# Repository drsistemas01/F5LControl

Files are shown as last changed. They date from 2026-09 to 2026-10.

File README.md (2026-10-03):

<p align="center">
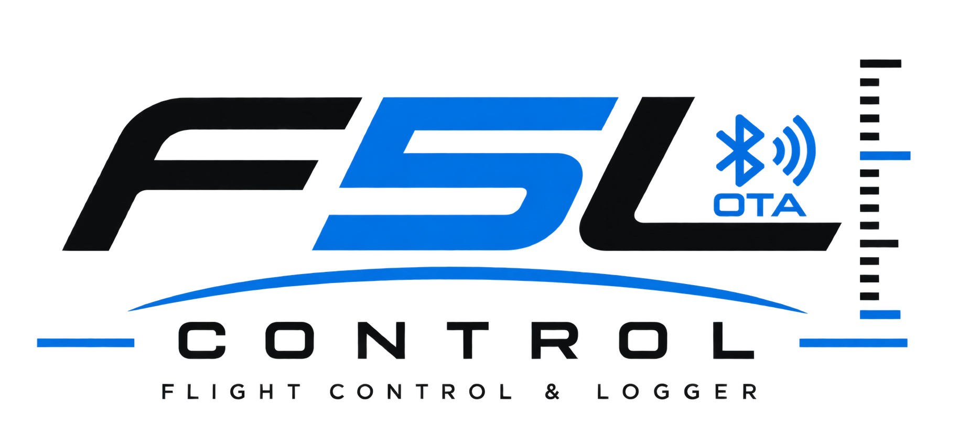
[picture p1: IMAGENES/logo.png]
F5LControl
  
</p>

<p align="center">
  
  
  
  
  
</p>

# F5LControl - Limitador F5L con ESP32-C3

**F5LControl** es un sistema limitador y datalogger para aeromodelismo en la categoría **F5L**, desarrollado sobre **ESP32-C3 Super Mini**.

El proyecto nació con el objetivo de disponer de un equipo **simple, económico y liviano**, capaz de controlar los parámetros de vuelo establecidos para F5L y, al mismo tiempo, registrar la información necesaria para poder **consultar y verificar el vuelo posteriormente**.

---

## Índice

- [Características](#características)
- [El sistema](#el-sistema)
- [Versión actual](#versión-actual)
- [Instalación](#instalación)
- [Uso básico](#uso-básico)
- [Modo Bluetooth](#modo-bluetooth)
- [Actualización por Bluetooth (OTA)](#actualización-por-bluetooth-ota)
- [Indicaciones del LED](#indicaciones-del-led)
- [Indicaciones de la pantalla (OLED)](#indicaciones-de-la-pantalla-oled)
- [Datos guardados en cada vuelo](#datos-guardados-en-cada-vuelo)
- [Hardware](#hardware)
- [Seguridad](#seguridad)
- [Categoría F5L](#categoría-f5l)
- [Carcasa 3D](#carcasa-3d)
- [Imágenes](#imágenes)
- [Tiempo estimado de grabación](#tiempo-estimado-de-grabación)
- [Apoyá el proyecto](#apoyá-el-proyecto)
- [Contacto y soporte](#contacto-y-soporte)
- [Agradecimientos](#agradecimientos)
- [Autor](#autor)

---

## 🎥 Canal de YouTube

Videos sobre **armado, configuración, actualización, pruebas de vuelo, funcionamiento y novedades** del proyecto **F5LControl**.

👉 **[Visitar F5LControl en YouTube](https://www.youtube.com/@F5LControl)**

---

## Características

- Corte de motor por altura.
- Corte de motor por tiempo.
- Registro de altura del vuelo.
- Registro de PWM de entrada desde receptor.
- Registro de PWM de salida hacia ESC.
- Descarga por Bluetooth BLE.
- Actualización de firmware por Bluetooth (OTA) — desde la versión 3.1.0.
- Web de control sin instalar programas.
- Exportación de vuelos `.vlo` y CSV.
- Barra de uso de memoria.
- Compatible con BMP180/BMP280/BME280/BMP580.
- Carcasa imprimible en 3D.

---

## El sistema

**F5LControl está compuesto por dos partes principales:**

### Firmware

Es el software que se instala directamente en el **ESP32-C3** y se encarga del funcionamiento del dispositivo.

Entre sus funciones se encuentran:

* Control del limitador.
* Medición y registro de altura.
* Control de los parámetros de vuelo.
* Registro de vuelos.
* Almacenamiento de los datos para su posterior consulta.
* Comunicación con la interfaz Web Control.

### Web Control

Es la interfaz utilizada para comunicarse con el dispositivo y administrar **F5LControl** de una manera sencilla, sin necesidad de instalar software adicional.

Desde la Web Control es posible:

* Configurar los parámetros del dispositivo.
* Consultar el estado y la información del equipo.
* Acceder al **datalogger**.
* Visualizar los vuelos registrados.
* Analizar y verificar los datos de cada vuelo.

### Contenido del repositorio

Este repositorio público contiene todo lo necesario para instalar y utilizar **F5LControl**:

* Binarios del firmware listos para instalar.
* Web Control.
* Manuales de instalación y utilización.
* Imágenes y documentación del proyecto.
* Normativas relacionadas con F5L.
* Archivos **STL** para impresión 3D de la carcasa.

> **Nota:** el repositorio no incluye el código fuente del firmware.

---

## Versión actual

**VERSION FW:** `3.1.10`  
**VERSION WEB:** `3.1.14`

**Historial de cambios**
- [Historial de cambios del firmware](docs/history_FW.md)
- [Historial de cambios de la web](docs/history_WEB.md)

**¿Cómo actualizo?**

**FW:** seguir el manual de flasheo:  
[Manual_Flasheo_ESP32-C3.pdf](https://github.com/drsistemas01/F5LControl/blob/main/FW/Manual_Flasheo_ESP32-C3.pdf)

**WEB:** descargar el archivo `index.html`:  
[WebControl - descarga directa](https://github.com/drsistemas01/F5LControl/raw/main/WEB%20Control/index.html)

---

## Instalación

### Archivos

**Firmware:** los binarios están en la carpeta `FW/BIN` y el manual de instalación en `FW/Manual_Flasheo_ESP32-C3.pdf`.

**Web de control:** el archivo `WEB Control/index.html`. Abrir con Chrome o Edge compatible con Web Bluetooth.

### Flasheo

> **LEER ANTES DE FLASHEAR**
>
> Antes de conectar la placa o cargar los binarios, leer el manual de instalación del firmware:
>
> `FW/Manual_Flasheo_ESP32-C3.pdf`
>
> Ahí está explicado el paso a paso completo para instalar el FW correctamente.

Cargar los binarios en estas direcciones:

| Dirección | Archivo |
|---|---|
| `0x0` | `bootloader.bin` |
| `0x8000` | `partitions.bin` |
| `0x10000` | `firmware.bin` |

No activar:

- Secure Boot
- Flash Encryption
- Encrypt
- eFuse
- opciones de seguridad permanente

Para uso normal, solo hacer flasheo estándar.

### Qué permite la web

- conectar por Bluetooth BLE
- listar vuelos guardados
- descargar vuelos
- exportar vuelos `.vlo`
- exportar CSV
- ver gráfica de altura
- ver PWM de entrada y salida
- identificar corte de motor
- calcular zoom/inercia posterior al corte
- ver tiempo de vuelo en planeo
- ver uso de memoria
- borrar vuelos
- revisar configuración del firmware

---

## Uso básico

1. Encender la placa con la radio encendida y el acelerador al mínimo.
2. Durante el arranque (aproximadamente 2 segundos), el equipo calibra el mínimo del acelerador y el barómetro.
3. Si detecta barómetro OK, memoria OK, señal PWM válida y mínimo válido, entra en modo vuelo.
4. Si algo falla, entra en modo Bluetooth y muestra el motivo en la pantalla (ver Modo Bluetooth).
5. Para entrar a Bluetooth a propósito (bajar vuelos o configurar), encender con la radio apagada.

> El botón BOOT queda reservado y no interviene en el arranque.

---

## Modo Bluetooth

Para entrar en modo Bluetooth:

1. Encender la placa con la **radio apagada**.
2. Esperar que el LED (parpadeo rápido) o la pantalla (logo de Bluetooth) indiquen Bluetooth activo.
3. Abrir la web de control.
4. Presionar conectar.
5. Elegir el dispositivo ESP32-FLIGHT.

Desde la web se pueden descargar vuelos, revisar la configuración y ver los datos del receptor.

Cuando el equipo entra en modo Bluetooth, el modo vuelo queda bloqueado y el motor no puede arrancar desde el limitador. Para volver a modo vuelo, reiniciar la placa con la **radio encendida** y el acelerador al mínimo.

---

## Actualización por Bluetooth (OTA)

<p align="center">
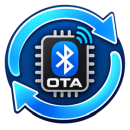
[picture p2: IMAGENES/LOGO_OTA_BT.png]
OTA por Bluetooth
  
</p>

> ✅ Disponible **a partir de la versión 3.1.0** del firmware.

**OTA** (del inglés *Over-The-Air*, "por el aire") significa que el equipo puede **actualizar su firmware por Bluetooth, sin cables ni programas**. Se hace desde la misma **Web Control**, en el celular o la PC.

### Dos formas de actualizar

- **Automática (la más fácil):** con el botón **"Buscar actualizaciones"**, la web mira si hay una versión más nueva publicada y, si la hay, **descarga e instala la última versión disponible** sola, con barra de progreso.
- **Por archivo (avanzada):** subís vos un archivo `firmware.bin` y la web lo instala. Sirve para **volver a una versión anterior** (rollback) o para probar una versión puntual que no sea la última.

En las dos, durante la actualización la pantalla del equipo muestra **UPDATE** con el porcentaje. Si algo se corta o falla, **no pasa nada**: el equipo sigue con la versión anterior (la nueva recién queda activa cuando se verificó completa).

### Seguridad

- El equipo **no está "escuchando" actualizaciones** todo el tiempo: la OTA se inicia **solo cuando vos se lo pedís** desde la web.
- La imagen se valida (tamaño + verificación de integridad) **antes** de activarse.

### ⚠️ Importante: el salto a la 3.1.X se hace una vez por cable

Como la versión **3.1.X cambió la organización interna de la memoria** (para poder tener dos firmwares y hacer OTA seguro), **la primera vez que pasás de una versión 3.0.X a la 3.1.X hay que flashear por USB**.

En ese flasheo por cable es **obligatorio grabar los 3 archivos** siguiendo el **manual de flasheo**:

- `bootloader.bin`
- `partitions.bin`
- `firmware.bin`

> ⚠️ No alcanza con grabar solo el `firmware.bin`: sin la tabla de particiones nueva (`partitions.bin`) el equipo no arranca ni queda habilitado el OTA.

A partir de ese flasheo, **todas las actualizaciones siguientes ya son por Bluetooth**.

> En resumen: **3.0.X → 3.1.X = por cable, los 3 `.bin` según el manual (una sola vez)**. **3.1.X → 3.1.Y en adelante = por Bluetooth (OTA)**.

---

## Indicaciones del LED

| Estado | LED |
|---|---|
| Ventana de arranque | Parpadeo lento |
| Bluetooth activo esperando conexión | Parpadeo rápido |
| Bluetooth conectado | Patrón SOS |
| Vuelo normal | LED fijo |
| Hubo rearranque | Parpadeo rápido |

---

## Indicaciones de la pantalla (OLED)

Si el equipo tiene pantalla, muestra:

| Momento | Pantalla |
|---|---|
| Al encender | Logo **F5L / CONTROL** con la versión |
| Listo para volar | Altura en metros (número grande) + tilde de OK |
| En vuelo (con motor) | Apagada (se enciende sola al aterrizar) |
| Al terminar el vuelo | **VÁLIDO** o **NULO**, alternando **altura máxima** y **zoom** (trepada por inercia) |
| Modo Bluetooth | Logo de Bluetooth + nombre del equipo (**CONECTADO** al vincular la app) |
| Falla de arranque | **E1** sin barómetro · **E2** mínimo del acelerador fuera de rango · **E3** memoria |

La altura a la que la pantalla se enciende sola al aterrizar es configurable desde la web (hasta 10 m; 10 m por defecto).

---

## Datos guardados en cada vuelo

Cada vuelo registra:

- tiempo
- altura
- PWM de entrada desde receptor
- PWM de salida hacia ESC
- motivo de corte

Los vuelos se guardan en memoria interna del ESP32-C3 y se descargan por Bluetooth desde la web.

---

## Hardware

### Placa usada

Placa recomendada:

**ESP32-C3 Super Mini con o sin pantalla OLED integrada**

Compatible con versiones con o sin pantalla.

La pantalla no es necesaria para el funcionamiento del limitador.

Características usadas:

- ESP32-C3
- 4 MB Flash
- USB nativo
- Bluetooth BLE
- GPIO con lógica de 3.3 V

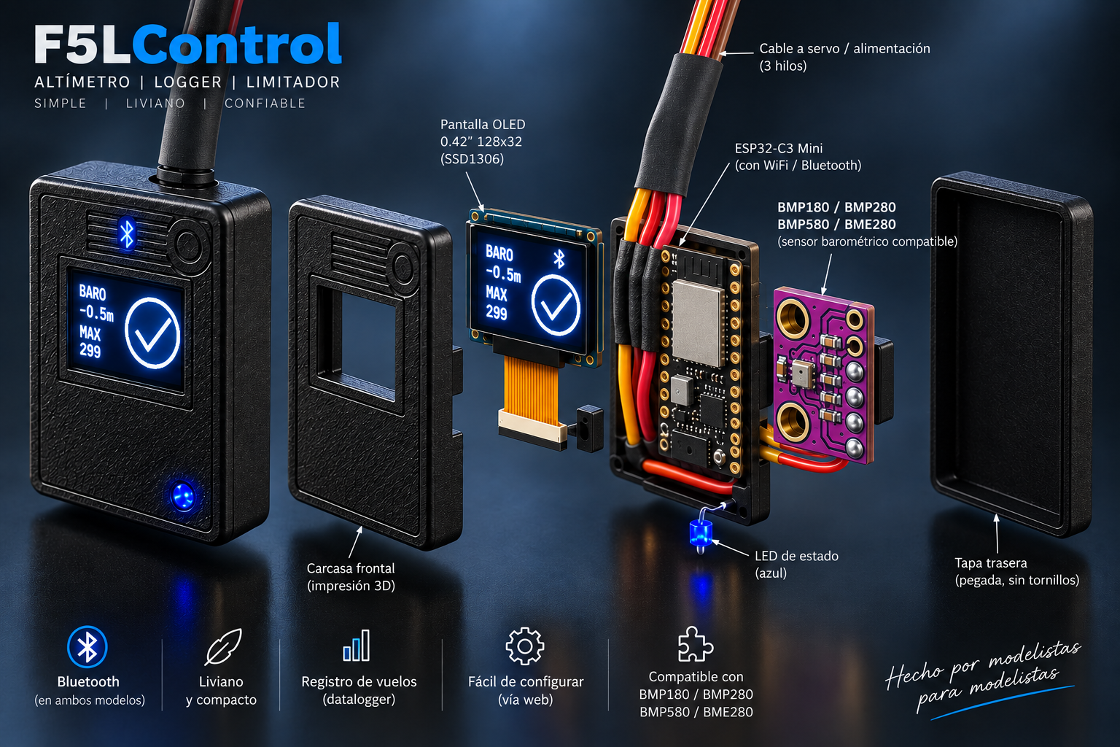
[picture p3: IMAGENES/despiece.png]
Despiece


### Pines

| Función | GPIO |
|---|---|
| Entrada PWM desde receptor | GPIO 3 por defecto. Configurable: GPIO 0, 1, 3, 4, 7 o 10 |
| Salida PWM hacia ESC | GPIO 4 por defecto. Configurable: GPIO 0, 1, 3, 4, 7 o 10 |
| SDA barómetro | GPIO 5 |
| SCL barómetro | GPIO 6 |
| LED de estado | GPIO 8 |
| Botón BOOT (reservado) | GPIO 9 |

Pines permitidos para entrada PWM y salida ESC desde configuración avanzada:

- GPIO 0
- GPIO 1
- GPIO 3
- GPIO 4
- GPIO 7
- GPIO 10

No usar el mismo pin para entrada PWM y salida ESC.

### Conexión básica

**Receptor RC**

| Receptor | ESP32-C3 |
|---|---|
| Señal PWM | GPIO configurado como entrada PWM, por defecto GPIO 3 |
| GND | GND |

La masa del receptor, ESC y ESP32-C3 debe estar en común.

**ESC**

| ESP32-C3 | ESC |
|---|---|
| GPIO configurado como salida ESC, por defecto GPIO 4 | Señal PWM |
| GND | GND |

**Barómetro**

Sensores soportados: BMP180, BMP280, BME280, BMP580. El firmware detecta automáticamente cuál está conectado al iniciar.

| Barómetro | ESP32-C3 |
|---|---|
| VCC | VCC |
| GND | GND |
| SDA | GPIO 5 |
| SCL | GPIO 6 |

### Receptores probados

Voy a ir actualizando esta lista con receptores probados.

Importante: no asumir que cualquier receptor es compatible. Un receptor solo debe conectarse directo si su salida PWM fue verificada en 3.3 V o menos. Si la salida PWM supera 3.3 V, puede dañar el ESP32-C3 y debe usarse adaptación de nivel.

| Marca | Modelo |
|---|---|
| CORONA | R4SF - R6SF - R8SF |
| FRSKY  | RX6R |

Si probaste un receptor, podés informar el resultado a **soporte.f5lcontrol@gmail.com** (marca y modelo, si funcionó, fallas encontradas y sugerencias).

---

## Seguridad

### Advertencia importante sobre PWM

La entrada PWM del receptor va directa al ESP32-C3.

> **ATENCION / CUIDADO**
>
> No todos los receptores son compatibles para conectarlos directo al ESP32-C3.
> Si el receptor entrega una señal PWM superior a 3.3 V, puede quemar el ESP32-C3.

**El pulso PWM del receptor NO debe superar 3.3 V.**

El ESP32-C3 no tolera 5 V en sus GPIO. Si se conecta una señal PWM de 5 V, o cualquier señal superior a 3.3 V, directamente al pin de entrada, se puede quemar la placa.

Algunos receptores entregan PWM a 3.3 V y otros pueden entregar PWM a 5 V. Antes de conectar cualquier receptor al limitador, hay que medir o verificar el nivel real de la señal PWM.

Antes de conectar un receptor:

1. Verificar el nivel de señal PWM.
2. Confirmar que el pulso sea de 3.3 V o menor.
3. No conectar señales PWM superiores a 3.3 V directo al ESP32-C3.
4. Si el receptor entrega PWM de 5 V, usar adaptación de nivel antes de conectarlo.

### Antes de volar

Realizar todas las pruebas de banco siempre **sin hélice**.

Antes de volar verificar:

- señal PWM máxima 3.3 V
- masa común entre receptor, ESC y ESP32-C3
- barómetro detectado
- respuesta correcta del ESC
- sentido correcto del acelerador
- funcionamiento del corte
- batería adecuada
- carcasa correctamente fijada

El uso en vuelo es responsabilidad del usuario.

### Cómo reiniciar el equipo

> ⚠️ **Bajo ningún motivo reinicies la placa con el botón de RESET (RST).**

**Versión CON pantalla (LCD):** para reiniciar, usá **siempre el botón BOOT** manteniéndolo apretado (el tiempo configurado, 2 s por defecto) **con la pantalla encendida** (es decir, en el piso). Eso hace un **reinicio controlado**: primero **cierra y graba el vuelo**, pone el **motor en mínimo (failsafe)** y **recién ahí reinicia**. Seguro y sin perder datos. Se puede habilitar/deshabilitar y ajustar el tiempo desde la web (sección "Pantalla").

**Versión SIN pantalla:** el reinicio controlado con el botón **NO funciona** (necesita la pantalla). En ese caso, **el único medio de reset es desconectar la batería** — **no** usar el botón RST.

**Por qué evitar el RST:** reinicia el micro **de golpe** → si estabas en un vuelo podés **perder los últimos datos** que no se alcanzaron a grabar, y el ESC puede recibir un transitorio en el arranque.

---

## Categoría F5L

F5LControl está diseñado para trabajar con los parámetros usados en F5L.

| Requisito | Valor |
|---|---:|
| Corte por altura | 90 m |
| Corte por tiempo de motor | 30 s |
| Referencia de altura inicial | estabilizada durante la ventana inicial de 2 s |
| Registro posterior del vuelo | sí |
| Verificación posterior del vuelo | sí |
| Barómetro | BMP180/BMP280/BME280/BMP580 |
| Pantalla | Opcional |

El firmware fue diseñado y compilado para cumplir los requisitos funcionales solicitados por FAI/CIAM para esta categoría: limitación por altura/tiempo, registro de datos y posibilidad de verificación posterior.

> Nota: este repositorio no declara una homologación oficial. Para competencia formal, verificar siempre contra la normativa vigente publicada por FAI/CIAM.

Referencia: [FAI Sporting Code - Aeromodelling / CIAM](https://www.fai.org/page/sporting-code)

**Normativas:** la carpeta `NORMATIVAS` incluye documentación de referencia relacionada con F5L y especificaciones del sistema.

---

## Carcasa 3D

Carpeta: `CARCASAS/STL`

Archivos incluidos:

Version sin Pantalla
- `CASE_SIN_LCD_BASE.stl`
- `CASE_SIN_LCD_TAPA.stl`

Version Con Pantalla
- `CASE_OLED_BASE.stl`
- `CASE_OLED_TAPA.stl`

---

## Imágenes

### Web de control

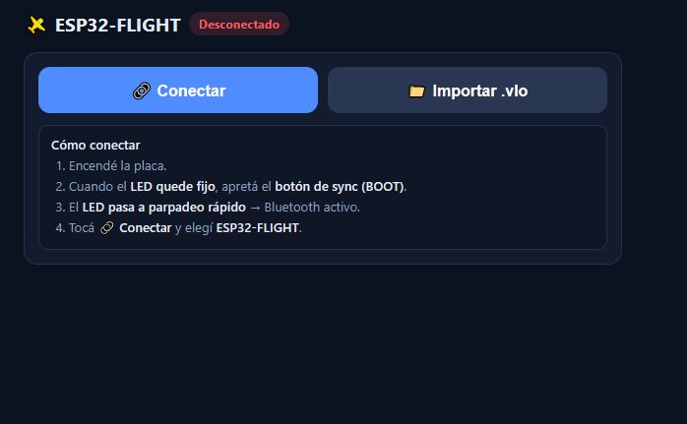
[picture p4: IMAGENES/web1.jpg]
Web 1


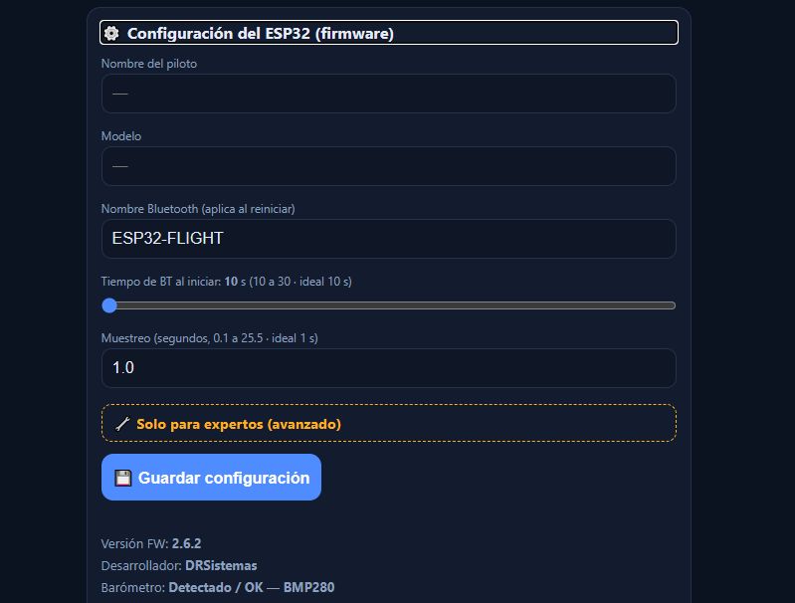
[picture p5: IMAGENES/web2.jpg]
Web 2


### Gráficas

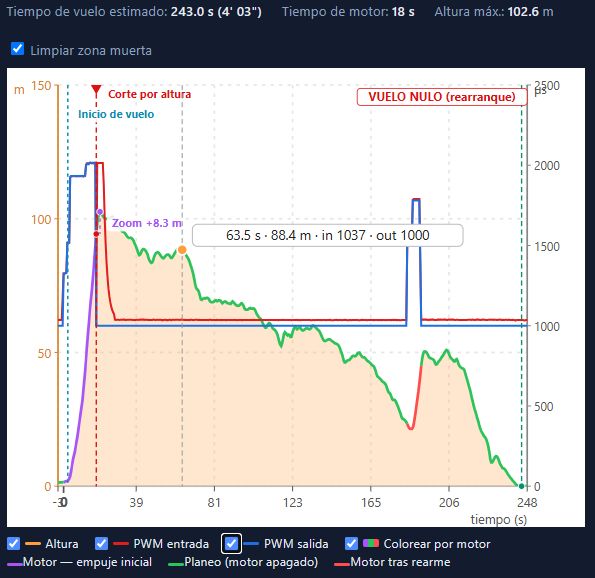
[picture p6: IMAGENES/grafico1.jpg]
Grafico 1


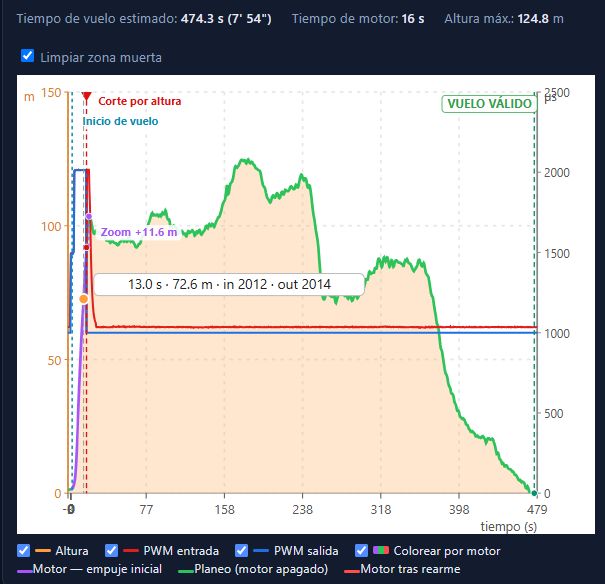
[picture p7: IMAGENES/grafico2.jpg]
Grafico 2


### Carcasa

Version OLED

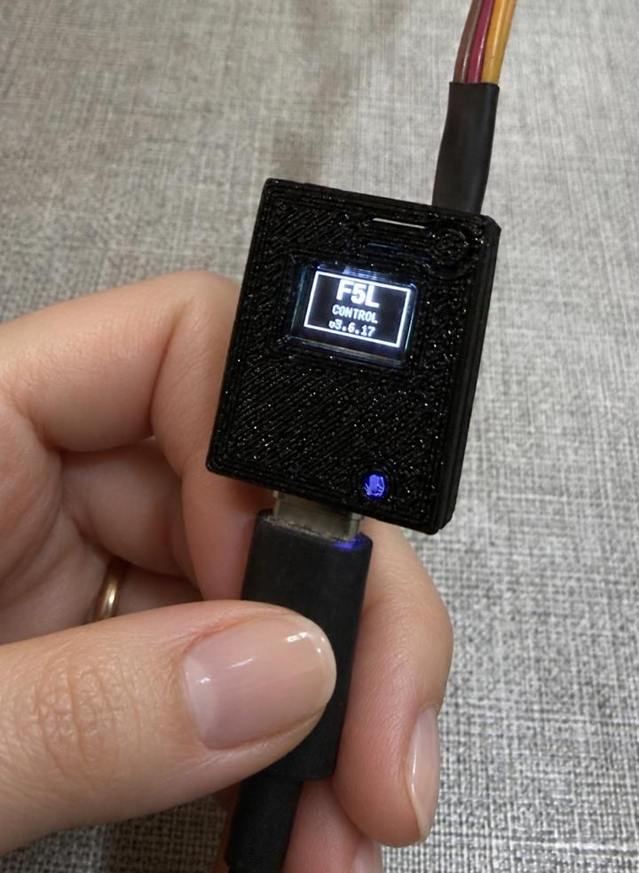
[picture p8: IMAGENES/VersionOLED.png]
Case indoor


Version Sin Pantalla

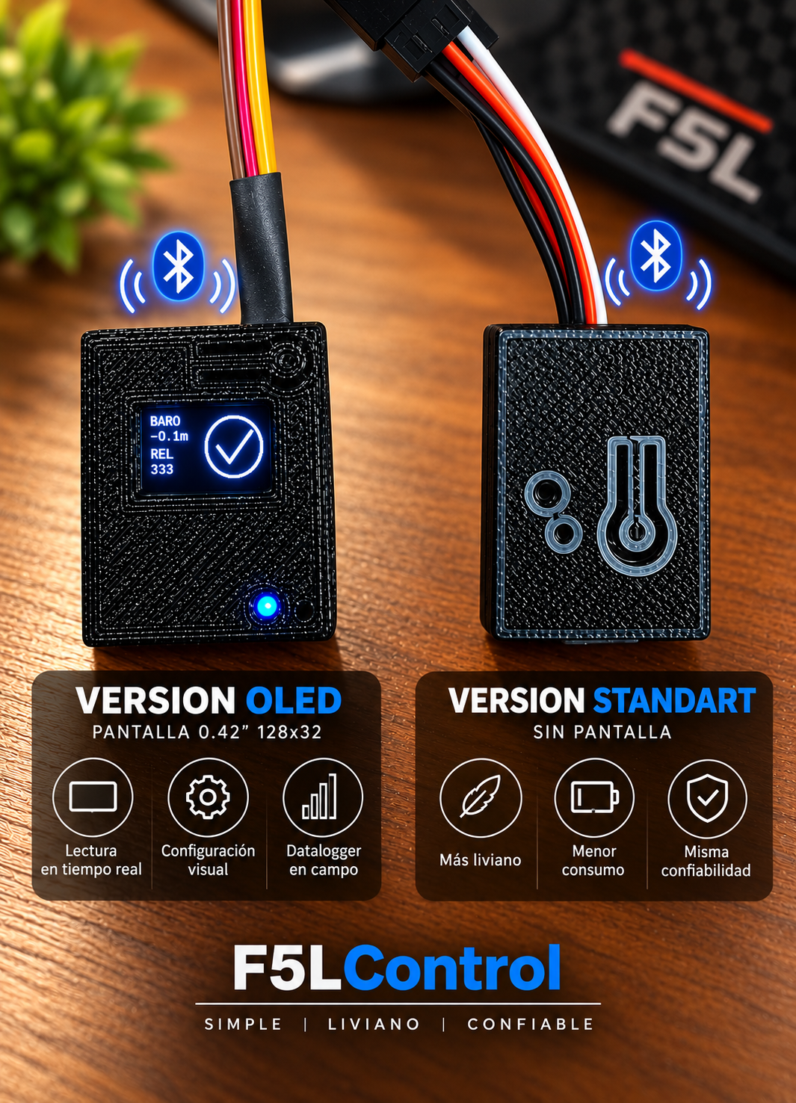
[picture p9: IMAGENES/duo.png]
Case LED


---

## Tiempo estimado de grabación

Los siguientes valores son estimativos. El tiempo real puede variar según la memoria libre disponible, la cantidad de vuelos guardados, el formato interno del archivo y el uso del sistema de archivos.

La tabla está calculada con aproximadamente 896 KB libres y registros VLO2 de 6 bytes.

| Intervalo de muestreo | Tiempo estimado de grabación |
|---:|---:|
| 0.1 s | 4 h |
| 0.5 s | 21 h |
| 1 s | 42 h |
| 2 s | 85 h |
| 5 s | 212 h |

---

## Apoyá el proyecto

F5LControl es un proyecto **libre y gratuito**. La idea es que cualquier aeromodelista pueda armar su propio limitador F5L de forma segura, funcional y a un costo accesible para la categoría, con componentes fáciles de conseguir, firmware ya compilado, web de control y archivos de carcasa para impresión 3D.

**Detrás de cada mejora hay muchas horas de programación, vuelos de prueba, componentes y prototipos.** Si el proyecto te resultó útil, te ayudó en tus vuelos o simplemente te gusta la idea, podés colaborar con el monto que quieras. Cada aporte ayuda a comprar nuevos sensores y placas, realizar más pruebas y seguir sumando mejoras para todos.

### ☕ Invitame un café y apoyá el proyecto

* [Donar con Mercado Pago (donaciones en pesos desde Argentina)](https://mpago.la/1ow62Ju)
* [Apoyar mediante GitHub Sponsors (donaciones internacionales en dólares)](https://github.com/sponsors/drsistemas01)

**Donar es totalmente opcional.** F5LControl seguirá siendo gratuito, completo y disponible para toda la comunidad.

---

## Contacto y soporte

Email: **soporte.f5lcontrol@gmail.com**

Este proyecto es libre y gratuito. No se solicita ningún pago por su uso.

Lo único que se pide es colaborar enviando por email:

- fallas encontradas
- mejoras sugeridas
- receptores probados
- receptores no compatibles o que no funcionaron
- nivel PWM medido
- comentarios o agradecimientos

Esta información ayuda a mantener actualizada la lista pública de receptores probados y a mejorar el proyecto para toda la comunidad.

---

## Agradecimientos

- **Cristian L. (Sunchales, Santa Fe, Argentina)** — Un agradecimiento especial por impulsar la idea inicial de que era posible crear un altímetro de bajo costo y accesible para todos los participantes de la categoría, y por brindarme su asesoramiento desde las primeras etapas del proyecto con la plataforma Arduino.

- **Pablo B. y Guillermo F. (Gran Santiago, Chile)** — Un agradecimiento especial por su aporte en la evolución del proyecto hacia la plataforma ESP32, acompañándome en las pruebas masivas, la validación y las mejoras del código y el hardware.

---

## Autor

**Desarrollo: DRSistemas / JMG**  
**Tandil · Bs. As. · Argentina**  
**GIT: github.com/drsistemas01/F5LControl**  
**Proyecto orientado a aeromodelismo F5L con ESP32-C3.**

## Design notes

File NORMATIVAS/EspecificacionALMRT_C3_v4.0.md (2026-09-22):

# Especificación ALMRT — ESP32-C3 Super Mini

## 1. Alcance

El ALMRT (*Altitude Limiter / Motor Run Timer*) es un dispositivo intercalado entre el receptor RC y el ESC de un planeador eléctrico. Limita el lanzamiento por tiempo de motor y por altura, registra los datos del vuelo y permite su verificación posterior.

Esta especificación es autosuficiente. Define qué debe hacer el dispositivo y sobre qué plataforma. No requiere código ni documentos de referencia: el algoritmo del número de serie (§5.1) incluye constantes, convenciones aritméticas y vectores de prueba verificados.

**Plataforma:** ESP32-C3 Super Mini, ESP-IDF nativo, driver propio del sensor.

---

## 2. Cumplimiento normativo

Categoría de referencia: **F5L**. Los parámetros son configurables en compilación para otras categorías.

### 2.1. De SC4_Vol_EDIC_26 Sección 7 — F5L Time & Height Limiter

| Requisito | Valor | Punto |
|---|---|---|
| Corte de motor | 30 s **o** 90 m, lo que ocurra primero | 2.3 |
| Referencia de altura cero | Máx. 2 s tras aplicar alimentación; sin responder a señal de motor durante ese lapso | 2.5 b/e |
| Salida antes del arranque | ≤ 0,9 ms | 2.5 d |
| Umbral de motor-on | 1,2 ms; histéresis permitida | 2.6.1 / 2.6.2 |
| Tasa de muestreo | ≥ 10 muestras/s | 2.3 |
| Precisión de tiempo | ≤ 0,1 s | 2.3 |
| Precisión de altura | ±2,5 m (2.3.1); "mejor que 2 m" (2.1.1 d) | — |
| Error de cómputo ISA | ±0,5 m | 2.4.5 |
| Rango de presión válido | 750 a 1050 hPa | 2.1.1 d.1 |
| Rango de temperatura | 0 a +50 °C | 2.3.1 |
| Rearranque | Prohibido tras el corte definitivo | 2.6.1 c |
| Display | **Opcional** en F5L | 2.1.2 e |
| Indicación de armado | Claramente visible para el competidor al alimentar | 2.5 a |
| Filtrado | Rechazo de transitorios permitido (2.1.1 c); **suavizado/promediado prohibido** (2.4.6) | — |
| Oversampling del sensor | Permitido | 2.4.7 |
| Alimentación | Desde la salida del receptor hacia el ESC | 2.1.2 c |
| Conectores | JR/Futaba, a prueba de desalineación | 2.1.2 |
| Instalación | ESC siempre en serie con el ALMRT | — |
| Blindaje del sensor | Protegido de luz fuerte y de presión ajena a la altura; venteo adecuado | 2.4.8.2 / 3.1.4 |

**Interpretación de la contradicción sobre filtrado.** El punto 2.1.1 c) exige rechazo de transitorios; el 2.4.6 prohíbe filtrado o suavizado. No son incompatibles: describen operaciones distintas.

- **Rechazo** — descartar una muestra físicamente imposible. La muestra del pico es válida, no se toca. **Permitido.**
- **Suavizado** — promediar muestras vecinas. Altera la muestra del pico. **Prohibido.**

Criterio de corte (2.3.4): ningún procesamiento puede modificar la altura máxima tal como la detectaría la muestra individual que representa el pico.

*Nota: 2.1.1 c) menciona "staging" como ejemplo de evento dinámico, terminología de cohetería — es arrastre de la Sección 2 (modelos espaciales). La doble cifra de precisión (2 m / 2,5 m) tiene el mismo origen. Se diseña contra los 2 m.*

### 2.2. De SC4_VOL_F5_ELECTRIC_26 punto 5.5.12.7

Requisitos no cubiertos por la Sección 7 del EDIC:

- Sin telemetría durante el vuelo de competencia
- Sin cambio de valores de ajuste desde el transmisor
- **Almacenamiento del último vuelo: punto de encendido y de apagado del motor, altura y tiempo**
- El dispositivo debe poder verificarse después del vuelo

5.5.12.8 b): **reset manual**; por transmisor está prohibido. En este diseño el reset es el ciclo de alimentación — quitar y reconectar la ficha, presenciado por el cronometrista.

### 2.3. Contradicción normativa a resolver

El rearranque está **habilitado por defecto** por reglamento GVRA, pero EDIC 2.6.1 c) lo prohíbe.

**Resolución:** parámetro de compilación. Valor por defecto *permitido*. Para presentación a homologación FAI debe compilarse en falso.

---

## 3. Configuración

Todos los parámetros son constantes de compilación. Cualquier cambio requiere recompilar y genera una nueva versión de firmware. **No existe mecanismo de configuración en campo.**

### 3.1. Reglamentarios

| Parámetro | Valor | Justificación |
|---|---|---|
| Tiempo máximo de motor | 30 000 ms | Reglamento F5L |
| Altura máxima de motor | 90 m | Reglamento F5L |
| Duración de cuarentena | 10 000 ms | Práctica de la categoría (ver §11.5) |
| Rearranque | Permitido | Reglamento GVRA |

### 3.2. Acelerador

| Parámetro | Valor | Descripción |
|---|---|---|
| Umbral de arranque | 1200 µs | Apagado → encendido |
| Umbral de apagado | 1190 µs | Encendido → apagado (10 µs de histéresis) |
| Umbral inicial | 1150 µs | Límite superior del acelerador inicial válido en el armado |
| Señal de override | 900 µs | Salida con motor apagado (máximo FAI) |
| Rango mínimo de pulso | 800 µs | — |
| Rango máximo de pulso | 2200 µs | — |
| Rango mínimo de frame | 13 500 µs | Cubre receptores Futaba S-FHSS y modos legacy (~14 ms) con margen |
| Rango máximo de frame | 25 000 µs | Límite superior del rango estándar RC |
| Frescura de acelerador | 300 ms | Límite ante pérdida de señal, no latencia esperada |

**Los tres umbrales no son intercambiables.** Cada uno se usa únicamente en la etapa que indica esta especificación.

### 3.3. Presión

| Parámetro | Valor | Descripción |
|---|---|---|
| Estabilización del sensor | 200 ms | Descarte inicial de lecturas |
| Duración de obtención de presión de piso | 1 000 ms | Total, incluida la estabilización |
| Cantidad mínima de muestras de piso | 10 | Si no se alcanza → bloqueo terminal |
| Intervalo mínimo entre muestras de piso | 40 ms | **Recalcular para C3 — ver §14.2** |
| Frescura de presión | 100 ms | Garantiza ≥10 muestras/s del EDIC |
| Timeout de validez de presión de piso | 300 000 ms | Desde la medición hasta el arranque. Si expira → bloqueo terminal |
| Rango válido de presión | 75 000 a 105 000 Pa | EDIC 2.1.1 d.1 |

### 3.4. Plataforma

| Parámetro | Valor |
|---|---|
| Velocidad del bus I2C | 50 kHz (50 % del estándar, por EMI del brushless) |
| Timeout de transacción I2C (`xfer_timeout_ms`) | 10 ms — **recalcular, ver §14.2** |
| Resolución RMT | 1 MHz (1 cuenta = 1 µs) |
| `signal_range_min_ns` | 2 000 ns (tope de hardware ≈ 3,2 µs) |
| `signal_range_max_ns` | 5 000 000 ns |
| Frecuencia LEDC | 50 Hz |
| Resolución LEDC | 14 bits (máximo del C3) |
| Oversampling de presión | ×8 |
| Oversampling de temperatura | ×8 |
| Filtro IIR del sensor | **Desactivado** (es suavizado — EDIC 2.4.6) |
| Modo del sensor | Normal, standby mínimo |

---

## 4. Hardware

### 4.1. Componentes

| Cant. | Componente | Función |
|---|---|---|
| 1 | ESP32-C3 Super Mini | Procesador, USB-C nativo, LED en GPIO8 |
| 1 | Módulo BMP280 3,3 V, 6 pines | Sensor (con pull-ups I2C y capacitor a bordo) |
| 1 | Resistencia 10 kΩ | Serie, entrada del receptor |
| 1 | Diodo Schottky BAT85 o BAT43 | Recorte de entrada a 3V3 |
| 1 | MOSFET N 2N7000 o BS170 (TO-92) | Salida al ESC |
| 1 | Resistencia 1 kΩ | Pull-up de drain al riel del BEC |
| 1 | Resistencia 10 kΩ | Pull-up de gate a 3V3 |
| 1 | Diodo Schottky 1N5817 o 1N5819 | Serie en alimentación |
| 1 | Capacitor electrolítico 470 µF / 10 V | Después del diodo serie |
| 1 | Capacitor cerámico 100 nF | En paralelo con el electrolítico |
| 1 | Buzzer activo | Indicación de rearranque (opcional) |
| 2 | Cables JR/Futaba (prolongación partida) | Entrada y salida |

### 4.2. Mapa de pines

| Función | Pin | Motivo |
|---|---|---|
| Entrada de acelerador | GPIO3 | Libre de rol de arranque. Crítico: la señal puede estar presente al energizar |
| Salida al ESC | GPIO10 | Libre de rol |
| SDA | GPIO0 | Libre de rol |
| SCL | GPIO1 | Libre de rol |
| Buzzer | GPIO4 | Reservado a JTAG; inactivo en operación |
| LED | GPIO8 | LED de placa, lógica invertida |

**No usar:** GPIO2 y GPIO9 (strapping), GPIO20 y GPIO21 (UART0).

**Ignorar la serigrafía de I2C.** Rotula SDA/SCL en GPIO8/GPIO9: GPIO8 es el LED y ambos son strapping. En el C3 el I2C se asigna por matriz a cualquier pin.

### 4.3. Alimentación

El positivo y la masa van **de conector a conector por cable directo**, sin pasar por las pistas de la placa. La corriente del receptor y los servos no circula por el ALMRT.

En la derivación hacia la placa, en este orden: Schottky en serie → 470 µF + 100 nF → pin 5V.

El diodo cumple cuatro funciones:

1. Retiene la alimentación de la placa ante caídas del riel por transitorios de servo (impide brownout)
2. Protege ante conexión de polaridad invertida
3. Impide que, al conectar el USB para leer el vuelo, se alimenten receptor y servos desde el puerto de la PC
4. Permite operar con BEC de 5 V o 5,5 V

El capacitor absorbe el ruido eléctrico de los servos; el cerámico complementa el filtro. Se documentaron combinaciones de ESC y servos capaces de reiniciar el microcontrolador sin este filtro.

**Advertencia heredada de v3.0 §13:** si el BEC es nominal de 5 V pero entrega menos, el diodo introduce una caída adicional contraproducente. Evaluar si la compatibilidad dual 5 V / 5,5 V es necesaria.

### 4.4. Entrada de acelerador

Señal del receptor → resistencia 10 kΩ → GPIO3. Diodo Schottky desde GPIO3 a 3V3, con la banda del lado del 3V3.

Acepta receptores de 3,3 / 4,8 / 5 / 6 V sin cambiar componentes. Corriente máxima con 6 V: 240 µA.

**No se usa pull-up interno.** El VIH del C3 es 0,75 × VDD = 2,475 V; un receptor de 3,3 V ya lo supera. El pull-up interno de 45 kΩ contra los 10 kΩ serie solo reduciría el margen del nivel bajo.

*El máximo absoluto de entrada del C3 es VDD + 0,3 = 3,6 V. El Schottky recorta en ~3,55 V. Un diodo de silicio común recortaría en 4,0 V, fuera de especificación.*

### 4.5. Salida al ESC

GPIO10 → gate del MOSFET. Source a masa. Drain al hilo de señal del ESC. Pull-up de 1 kΩ del drain al riel del BEC. Pull-up de 10 kΩ del gate a 3V3.

**Lógica invertida:** gate alto → salida baja. El firmware escribe el complemento.

*Por qué pull-up de gate y no pull-down:* durante los ~100 ms de arranque el GPIO está en alta impedancia. El pull-up mantiene el MOSFET conduciendo y la salida en bajo — el ESC no recibe señal válida y no arma.

*Por qué 1 kΩ y no 10 kΩ en el drain:* contra el pull-down interno típico de un ESC (~10 kΩ), un pull-up de 10 kΩ dejaría el nivel alto en la mitad de la tensión del BEC, y el flanco de subida sería lento.

La salida entrega la tensión del BEC, no 3,3 V. Esto garantiza compatibilidad tanto con ESC de lógica 5 V (umbral 3,5 V) como de lógica 3,3 V.

### 4.6. Sensor

VDD a 3V3, GND a GND, SDA a GPIO0, SCL a GPIO1. Montado sobre la placa, dentro del pod del modelo.

El pod cumple el blindaje de luz de EDIC 2.4.8.2 y define el venteo estático de 3.1.4.

El nivel alto del bus lo establecen las resistencias pull-up del módulo a 3,3 V.

### 4.7. Advertencia sobre la placa

La ESP32-C3 Super Mini **no tiene diseño oficial ni fabricante único**. Las variantes difieren en LDO, LED y protecciones.

- Contrastar el pinout con la serigrafía de cada lote
- Leer el modelo del regulador en el encapsulado antes de dar por buenos los 5,5 V del BEC (variantes con ME6211 rondan 6 V de máximo)
- **No hay diodo de protección entre el pin 5V y el VBUS del USB**: nunca alimentar por ambos simultáneamente

---

## 5. Identificación del dispositivo

### 5.1. Número de serie

Hash determinístico de 8 caracteres en base36 sobre los 26 bytes de coeficientes de calibración del BMP280, leídos por I2C desde el registro 0x88.

**Fundamento de la elección.** El C3 tiene MAC única en eFuse, pero **no viene protegida contra escritura de fábrica**: se pueden quemar bits adicionales, y el firmware puede reportar cualquier valor. El hash del sensor es más fuerte: el dato está en el silicio del BMP280, fuera del alcance del firmware. Un verificador que sospeche del firmware carga el suyo y obtiene el valor real.

Como cada dispositivo se ensambla con un único sensor y no se desensambla, el número de serie es único e invariante durante toda su vida útil.

El algoritmo es **invariante**: cualquier reimplementación debe producir exactamente el mismo hash, para preservar la continuidad del registro histórico.

#### 5.1.1. Constantes

| Nombre | Valor |
|---|---|
| OFFSET | `0xCBF29CE484222325` |
| PRIME | `0x100000001B3` |
| ALFABETO | `0-9A-Z` (36 símbolos, en ese orden) |

#### 5.1.2. Convenciones aritméticas

Aritmética entera sin signo de 64 bits con desborde modular (módulo 2⁶⁴). XOR bit a bit. El término `byte[i] × (i+1)` es máximo 6630 y no desborda; el desborde modular aplica al producto por PRIME.

#### 5.1.3. Algoritmo

```
funcion CalcularHashBase36(datos[0..N-1], N) -> cadena de 8 caracteres
    hash = OFFSET                        // uint64
    para i desde 0 hasta N-1:            // índice base 0
        termino = datos[i] * (i + 1)
        hash = (hash XOR termino) * PRIME    // XOR primero, luego multiplicar
        hash = hash mod 2^64
    fin para
    // 8 dígitos base36, del menos significativo al más significativo,
    // escritos de mayor a menor peso (posición 0 = más significativo)
    v = hash
    para p desde 7 hasta 0:
        salida[p] = ALFABETO[v mod 36]
        v = v div 36
    fin para
    devolver salida
fin funcion
```

Notas que eliminan ambigüedad: (1) el orden es XOR y luego multiplicación; (2) el índice es base 0; (3) la reducción equivale a tomar el hash módulo 36⁸, con relleno natural de ceros a la izquierda.

#### 5.1.4. Vectores de prueba

Una implementación correcta debe reproducir exactamente estas salidas sobre 26 bytes de entrada:

| Entrada | Salida esperada |
|---|---|
| `datos[i] = i` (0x00, 0x01, …, 0x19) | `V6MRUXJB` |
| `datos[i] = 0xFF` (los 26 bytes) | `Z71AVNXS` |
| `datos[i] = 0x00` (los 26 bytes) | `TS1HDN0T` |

*Estos tres vectores fueron verificados por ejecución independiente del algoritmo tal como está especificado arriba.*

#### 5.1.5. Manejo de error

Si la transacción I2C falla —NACK, lectura incompleta o timeout— el número de serie es la cadena centinela `ERROR000`.

No se garantiza la unicidad del hash ni que el fabricante produzca coeficientes únicos. Sobre más de 1000 sensores no se registraron colisiones. En caso de colisión, el sensor se descarta y se reemplaza.

### 5.2. Versión de firmware

La versión y los parámetros de la categoría están fijos en el código fuente. Cualquier cambio de parámetros o de comportamiento exige una versión nueva. Versión y parámetros son parte del mecanismo de identificación e integridad.

Como el dispositivo no tiene display, **la revisión de firmware debe estar impresa de forma permanente en el dispositivo** (EDIC 2.1.2).

### 5.3. Reporte serial

Al iniciar, el dispositivo emite por USB CDC un reporte con:

- Versión de firmware y parámetros de configuración activos
- Número de serie del sensor (puede ser `ERROR000`)
- Datos completos del último vuelo registrado, con alturas calculadas y tiempos en segundos

El reporte se emite **exista o no un host conectado**; el proceso continúa sin esperar confirmación. Al terminar se libera el puerto.

Se declara 115200 baudios por continuidad con el procedimiento de verificación existente. En USB CDC el valor es nominal y no afecta la velocidad real.

**El enlace es de solo lectura.** No existen comandos de escritura, por lo que no hay ajustes modificables por ningún medio (satisface EDIC 2.1 d y F5L 5.5.12.7 c).

Con esto se cumple el requisito de poder consultar los datos del último vuelo después del vuelo. El verificador conecta una terminal serial — por ejemplo un teléfono Android con cable OTG y una aplicación de terminal, o cualquier notebook.

**El ALMRT debe desconectarse del modelo antes de conectar el USB.** Esta instrucción debe figurar explícitamente en el procedimiento de verificación.

#### 5.3.1. Formato

```
ALMRT v14.0 - (c) Cristian Leiva

90 metros - 30 Segundos - Rearranque

Sensor           : BMP280

Serie Sensor     : HT7822E6

- Ultimo Vuelo -

Presion Inicial  : 1008.86

Presion Corte    : 998.10

Presion Zoom     : 995.67

Acelerador Inicial: 924

Acelerador Arranque: 1212

Acelerador Corte : 1592

Acelerador Maximo: 1632

Altura Corte     : 90.32

Altura Zoom      : 110.89

Tiempo Inicio    : 22.43

Tiempo Corte     : 10.33

Tiempo Rearranque: 0.00

Tiempo FailSafe  : 0.00
```

---

## 6. Sistema de indicadores

Dos indicadores físicos: **LED** (GPIO8, siempre presente, lógica invertida) y **buzzer** (GPIO4, opcional).

### 6.1. Modos

| Modo | LED | Buzzer |
|---|---|---|
| 0 | Apagado | Apagado |
| 1 | Activo | Inactivo |
| 2 | Activo | Activo |

### 6.2. Patrón de indicación de altura

Representa la altura zoom: la máxima lograda en todo el vuelo con motor más los 10 segundos de cuarentena. Se representa en tres dígitos decimales (centenas, decenas, unidades) emitidos en secuencia y repetidos en loop continuo. La altura es siempre diferencial respecto al piso —no negativa y dentro del rango reglamentario—, por lo que tres dígitos alcanzan.

Un **destello** es el ciclo completo de un estado apagado seguido de un estado encendido. Un **destello largo** es un encendido sostenido de cuatro estados consecutivos sin apagado previo.

- **Dígito 1 a 9:** N destellos consecutivos. El observador los cuenta.
- **Dígito 0 significativo:** un destello largo — cuatro estados encendidos, distinguible por su duración.
- **Dígito 0 no significativo** (ceros a la izquierda): silencio de cuatro estados apagados — misma duración que el destello largo, sin luz, para mantener el ritmo.

Entre cada par de dígitos se inserta una pausa. Al final del tercer dígito, una pausa larga antes de repetir, visualmente distinguible de la pausa entre dígitos.

La duración de cada estado es configurable en compilación y debe ser perceptible a simple vista.

### 6.3. Patrón de indicación de rearranque

Un estado encendido seguido de uno apagado, repetido en loop continuo. Destello simple y veloz, inconfundible con la codificación de dígitos.

### 6.4. Uso por etapa

| Momento | Modo | Contenido |
|---|---|---|
| Al encender | 1 | Altura zoom del vuelo anterior; si `TiempoRearranque > 0` → patrón de rearranque. Permanece hasta el arranque |
| Durante el vuelo activo | 0 | Detenido |
| Post-vuelo sin rearranque | 1 | Altura zoom del vuelo actual |
| Post-vuelo con rearranque confirmado | 2 | Patrón de rearranque, hasta el corte de energía |

La indicación de rearranque persiste en memoria no volátil y reaparece en cada encendido hasta completar un vuelo nuevo sin rearranque.

El LED encendido al alimentar satisface también el requisito de EDIC 2.5 a): indicación claramente visible de que el dispositivo está reseteado y armado.

### 6.5. Jerarquía de verificación de rearranque

Tres medios, en orden de inmediatez:

1. **Buzzer/LED** — audible y visible durante el evento en vuelo y al aterrizar
2. **LED** — visible al encender durante la inspección técnica
3. **Reporte serial** — verificación formal con todos los datos

---

## 7. Sistema de captura de acelerador

### 7.1. Contrato público

La consulta de acelerador retorna exclusivamente:

- **`0`** — no hay información confiable disponible (condición de failsafe, sin excepción)
- **800 a 2200** — valor válido en microsegundos

La decisión de qué hacer ante un `0` corresponde a la etapa que consulta (§11), no a esta función.

### 7.2. Garantías del valor retornado

Cuando el valor es distinto de `0`, cumple simultáneamente:

1. **Integridad del pulso** — la trama contiene exactamente un símbolo. Más de uno indica un flanco espurio que partió el pulso.
2. **Rango físico válido** — entre 800 y 2200 µs.
3. **Frame válido** — período entre flancos de subida consecutivos, dentro del rango configurado.
4. **Frescura** — menos de 300 ms de antigüedad.
5. **Representatividad estadística** — es la mediana de 3 muestras consecutivas válidas.

Si no puede garantizar las cinco, retorna `0`.

**Un pulso y un frame son magnitudes distintas, cada una con su propio rango de validez.** Un pulso pertenece a un frame porque comparten el mismo flanco de subida inicial.

### 7.3. Implementación sobre C3

La captura se realiza con el periférico **RMT en modo recepción** (canales 2 o 3 del C3; los canales 0 y 1 son solo transmisión). El MCPWM no existe en este chip.

**Configuración:**

- Resolución 1 MHz — cada cuenta es 1 µs, unidad natural del PWM de servo
- `signal_range_min_ns` = 2000 ns — filtro de glitches por hardware
- `signal_range_max_ns` = 5 000 000 ns — umbral de cierre de trama

**Sobre el umbral de cierre.** No es la duración del silencio: es cuánto silencio necesita observar el periférico antes de dar la trama por terminada. Debe ser mayor que el pulso más largo (2200 µs) y menor que el silencio más corto (13 500 − 2200 = 11 300 µs). El valor de 5000 µs queda holgado por ambos lados.

**Sobre el filtro de glitches.** Su tope de hardware es ≈3,2 µs (registro de 8 bits contando ciclos del APB a 80 MHz). No puede usarse como umbral de validez de 800 µs — y no debe: el filtro elimina la transición, de modo que un pulso espurio de 400 µs desaparecería sin dejar rastro. Con el filtro en 2 µs ese pulso llega al buffer, se descarta por rango, y puede contabilizarse.

**Ciclo de operación.** El driver detiene el receptor al cerrar cada trama; hay que relanzar la recepción. La ventana disponible es de ~7 ms, margen amplio sobre la latencia de una tarea de prioridad alta.

**Reconstrucción del instante del flanco de subida:**

```
t_flanco = t_cierre − ancho − (signal_range_max_ns / 1000)
```

**Modelo productor/consumidor.** Una tarea productora valida cada trama y publica `{ancho, t_flanco}` en un buffer rodante de las últimas 3 muestras válidas consecutivas. Si una muestra no supera la validación, el conteo de consecutivas se reinicia. La consulta verifica frescura y devuelve la mediana sin demora adicional.

El presupuesto de 300 ms es el límite ante pérdida de señal, no la latencia esperada. En régimen la latencia es de un frame.

### 7.4. Nota sobre la mediana y el retardo

En régimen la ventana de tres ya está llena: entra una muestra, sale la mediana. El retardo es de **un frame**, no de tres. Los tres frames son el llenado inicial, que ocurre segundos antes del lanzamiento.

Un retardo de un frame satisface EDIC 4.2.2 c) —la señal al ESC sigue a la señal de comando— con el mismo orden de retardo que introduce cualquier receptor.

**La mediana no se aplica por magnitud de salto.** Con una llave de dos posiciones el acelerador salta de 1000 a 2000 en un frame, y eso es legítimo. La mediana protege contra un valor espurio aislado, no contra cambios grandes.

---

## 8. Sistema de salida al ESC

### 8.1. Generación

Periférico **LEDC**, 50 Hz, 14 bits (máximo del ESP32-C3).

| Magnitud | Valor |
|---|---|
| Paso | 1,22 µs |
| Duty para 1000 µs | 819 |
| Duty para 2000 µs | 1638 |
| Fórmula | `duty = ancho_µs × 16384 / 20000` |
| Corrección por MOSFET inversor | `duty_escrito = 16383 − duty` |

Se escribe una vez y el hardware repite el pulso indefinidamente, sin intervención de la CPU. Solo se reescribe cuando el valor cambia.

*La resolución de 1,22 µs es peor que los 0,5 µs del hardware AVR anterior y no tiene consecuencia: el ESC no distingue esa diferencia y el EDIC exige 0,1 s de precisión temporal.*

### 8.2. Señal de override

Cuando el dispositivo debe mantener el motor apagado, emite el **acelerador inicial**. Este valor es 900 µs por defecto (máximo FAI para motor apagado, EDIC 2.5 d) y se reemplaza por el valor real obtenido en el armado.

### 8.3. Estado durante el arranque del firmware

Antes de que LEDC quede configurado, el GPIO está en alta impedancia. El pull-up de gate mantiene el MOSFET conduciendo y la salida en bajo. El ESC no recibe pulsos válidos y no arma. Este es el estado seguro y coincide con la lógica invertida en operación.

---

## 9. Medición de presión y cálculo de altura

### 9.1. Contrato de lectura

Mismo contrato que el acelerador: retorna **`0`** si no hay lectura confiable, o la presión compensada en Pascales.

Una lectura es válida si es un número real (no NaN) y está entre 75 000 y 105 000 Pa (EDIC 2.1.1 d.1). Las que no cumplen ambas condiciones cuentan como fallidas.

**Frescura:** menos de 100 ms de antigüedad. Esto garantiza la cadencia mínima de 10 muestras/s del EDIC.

### 9.2. Sensor

**BMP280 exclusivamente.** Direcciones 0x76 o 0x77 según el pin SDO del módulo; el firmware detecta cuál responde validando el Chip ID (registro 0xD0, valor 0x58).

**Driver propio, sobre ESP-IDF.** La compensación se implementa según el procedimiento publicado por Bosch en la hoja de datos del sensor. Para homologación, el EDIC exige la hoja de datos del fabricante como documentación de respaldo; un driver que sigue ese procedimiento es directo de defender.

**Configuración:** modo normal, muestreo continuo y autónomo, oversampling de presión ×8, de temperatura ×8, filtro IIR desactivado, standby mínimo. La lectura solo cosecha el último dato disponible.

El oversampling está expresamente permitido por EDIC 2.4.7. El filtro IIR desactivado no es opcional: es suavizado, prohibido por 2.4.6.

La temperatura se mide internamente para la compensación, por lo que la presión devuelta ya está compensada.

### 9.3. Rechazo de transitorios

Permitido y exigido por EDIC 2.1.1 c). Se descarta una muestra cuya tasa de cambio contra la anterior sea físicamente imposible para un planeador.

El criterio debe ser por **tasa de cambio físicamente imposible**, no por desviación estadística respecto de un promedio — esto último sería suavizado encubierto. El umbral debe documentarse: es lo que un evaluador va a querer ver.

**Prohibido:** promediar, media móvil, o cualquier operación que altere la muestra que representa el pico.

### 9.4. Cálculo de altura

Fórmula ISA del EDIC 2.4.1:

**h = 44330,76923 × (1 − (P / P₀)^0,190266669)**

Donde P es la presión medida y P₀ la presión de referencia del piso, ambas en Pascales. El cálculo es siempre diferencial respecto al piso.

Constantes: K1 = 44330,76923 m; K2 = 0,190266669.

**Las variables se implementan como `float` de 32 bits. Nunca `double`.** El ESP32-C3 no tiene FPU y emula el punto flotante por software; la doble precisión es sustancialmente más lenta. La precisión de `float` es suficiente para el ±0,5 m que exige EDIC 2.4.5.

*El ATmega328P tampoco tenía FPU, así que esto no es una regresión: el C3 emula 32 bits a 160 MHz contra 8 bits a 16 MHz.*

---

## 10. Persistencia

Se utiliza **NVS** sobre la flash interna. El almacenamiento por clave elimina la necesidad de asignar direcciones manualmente.

### 10.1. Datos persistidos

| Dato | Descripción |
|---|---|
| Presión inicial | Promedio de al menos 10 lecturas de presión de piso al arrancar. Referencia de todos los cálculos de altura |
| Presión de corte | Presión mínima registrada durante el vuelo con motor. Se inicializa a la presión inicial |
| Presión zoom | Presión mínima durante el vuelo con motor y los 10 s de cuarentena. Se inicializa a la presión inicial |
| Acelerador inicial | Valor de motor apagado del piloto. 900 µs por defecto, reemplazado al completar el armado |
| Acelerador de arranque | Valor en el momento del arranque |
| Acelerador de corte | Último valor antes del corte. Se inicializa al valor de arranque |
| Acelerador máximo | Máximo registrado durante el vuelo. Se inicializa al valor de arranque |
| Tiempo de inicio | Timestamp del arranque, en milisegundos |
| Tiempo de corte | Milisegundos desde el arranque hasta el corte |
| Tiempo de rearranque | Milisegundos desde el arranque hasta el rearranque. 0 si no hubo |
| Tiempo de failsafe | Milisegundos desde el arranque hasta el primer failsafe. 0 si no hubo |

### 10.2. Momento de escritura

Los datos se persisten **al finalizar la cuarentena**. El registro sobrevive al ciclo de alimentación y se sobrescribe recién en el vuelo siguiente. Alimentar el dispositivo nunca borra el registro: si lo hiciera, sería imposible cumplir F5L 5.5.12.7 e).

### 10.3. Precaución de IRAM

El ESP32-C3 es monocore. Durante una escritura a flash se detienen las interrupciones no marcadas como seguras para IRAM, por decenas de milisegundos en el peor caso.

**El callback de RMT y todo lo que invoque deben estar en IRAM** (`ESP_INTR_FLAG_IRAM`). Los datos constantes que el manejador use requieren `DRAM_ATTR` — el compilador puede ubicar en flash una constante aunque no esté marcada `const`.

*Mitigación de arquitectura:* la escritura ocurre al cerrar la cuarentena, con el vuelo con motor ya terminado y la salida al ESC fija por hardware. Solo es crítico si el rearranque está habilitado, porque en ese caso el acelerador sigue vigilándose después del corte.

---

## 11. Etapas operativas

El dispositivo ejecuta una secuencia lineal de etapas, sin retorno. El **bloqueo terminal** es una condición sin salida: el dispositivo mantiene el acelerador en el valor de acelerador inicial indefinidamente hasta que se corte la energía.

La etapa es una variable de estado compartida entre tareas. El bloqueo terminal es un estado que todas las tareas respetan, no un bucle infinito.

### 11.0. Acciones ante un valor `0` de las funciones de adquisición

| Etapa | Magnitud | Acción ante `0` |
|---|---|---|
| Presión de piso (11.1) | Presión | Descartar la muestra: no cuenta para el promedio |
| Armado / Arranque (11.2 / 11.3) | Acelerador | No se cumple la condición de avance; se sigue esperando (sujeto al timeout de validez de piso) |
| Vuelo con motor (11.4) | Acelerador | Failsafe: corte (override) + registro de tiempo de failsafe |
| Vuelo con motor (11.4) | Presión | Corte (override) + registro de tiempo de failsafe |
| Cuarentena (11.5) | Presión | Descartar la muestra |
| Post-vuelo (11.6) | Acelerador | Failsafe post-rearranque: override + registro de failsafe (1ª vez) |

### 11.1. Inicialización

**Configuración de hardware.** Pines, RMT, LEDC, I2C, NVS. Salida al ESC en 900 µs (override FAI).

**Lectura de NVS.** Carga los datos del último vuelo registrado.

**Indicación del vuelo anterior.** Modo 1 (solo LED). Si `TiempoRearranque > 0` → patrón de rearranque; si no → altura zoom del vuelo anterior, redondeada al entero más cercano y clampeada a 0–999. Permanece activa hasta el arranque.

**Verificación del sensor y número de serie.** Intenta el BMP280 en 0x76 y 0x77. Lee los 26 bytes de calibración desde 0x88 y calcula el número de serie. Si el sensor no responde, o falla la lectura de calibración → `ERROR000`.

**Reporte serial.** Emite el reporte incluyendo el número de serie. No bloqueante: no espera host.

**Bloqueo terminal.** Si el número de serie es `ERROR000` → bloqueo terminal inmediato.

**Establecimiento de referencia de altura.** Estabiliza el sensor 200 ms descartando lecturas. Luego, durante el resto de los 1000 ms, obtiene todas las muestras válidas posibles respetando el intervalo mínimo entre muestras. Si no se alcanzan 10 muestras válidas → bloqueo terminal. El promedio es la presión de referencia; `PresionCorte` y `PresionZoom` se inicializan a ese valor.

Inmediatamente arranca el contador de validez de presión de piso.

**Restricción de EDIC 2.5 b/e:** toda esta etapa debe completarse dentro de los 2 s desde la aplicación de alimentación, y durante ella el dispositivo no debe responder a ninguna señal de motor. Ver §13.1 sobre el presupuesto de arranque.

### 11.2. Armado

Espera que la consulta de acelerador retorne un valor distinto de `0` y menor al **umbral inicial**. El contador de validez sigue corriendo; si expira → bloqueo terminal.

Al obtenerlo, ese valor reemplaza al acelerador inicial (900 µs) y se replica inmediatamente a la salida del ESC.

### 11.3. Arranque

Espera acelerador **mayor al umbral de arranque**. El contador de validez sigue corriendo; si expira → bloqueo terminal.

Al detectar el arranque:

- Se registra el timestamp de inicio
- Se registran acelerador de arranque, de corte y máximo, todos al valor de arranque
- `PresionCorte` y `PresionZoom` se inicializan a `PresionInicial`
- Tiempos de corte, rearranque y failsafe se inicializan en cero
- El servicio de indicadores se detiene (modo 0)

### 11.4. Vuelo con motor

Monitoreo continuo:

**Acelerador.** Se replica al ESC en tiempo real. Se actualizan acelerador máximo y de corte.

**Failsafe RC.** Si la consulta retorna `0` → corte, registro de tiempo de failsafe, fin de etapa.

**Presión.** Muestreo continuo; actualiza `PresionCorte` y `PresionZoom` con el mínimo. Si la lectura retorna `0` → corte, registro de failsafe, fin de etapa.

**Corte reglamentario** — cualquiera de los tres termina la etapa:

- Altura calculada ≥ altura máxima configurada
- Tiempo transcurrido ≥ tiempo máximo configurado
- Acelerador ≤ umbral de apagado (el piloto corta)

Al salir, el acelerador se fija en el valor inicial.

*El corte por altura lo detecta la tarea de presión; el corte por tiempo y por acelerador, la tarea de acelerador. La rutina de corte debe ser atómica: dos tareas pueden alcanzarla.*

### 11.5. Cuarentena

10 segundos sin posibilidad de rearranque. El acelerador se mantiene en el valor inicial.

Continúa el muestreo de presión actualizando `PresionZoom` si se registra un nuevo mínimo.

Al finalizar se persisten todos los datos en NVS.

*Nota normativa: la ventana de 10 s proviene de la práctica de la categoría. El texto de la Sección 7 define la ventana de detección de pico hasta el cruce de la altura requerida (2.5), lo cual deja sin cerrar el caso de corte por tiempo por debajo de 90 m — que es el habitual. Los 10 s también figuran en 4.2.3 del EDIC, pero ese apartado describe el procedimiento de F5J. Ver §14.1.*

### 11.6. Post-vuelo

El acelerador se mantiene en el valor inicial. Los indicadores pasan a modo 1 mostrando la altura zoom del vuelo actual.

**Sin rearranque habilitado:** bloqueo terminal.

**Con rearranque habilitado:** el rearranque es un mecanismo de seguridad que permite al piloto recuperar el control del acelerador a costa de invalidar el vuelo.

Cuando el acelerador regresa a un valor menor al umbral inicial, el piloto puede optar por usar el mecanismo. Si luego sube por encima del umbral de arranque, el rearranque queda confirmado:

- Se registra el tiempo de rearranque
- Se persiste en NVS
- Los indicadores pasan a modo 2 con patrón de rearranque, para alertar al juez
- A partir de ahí el piloto tiene control directo del acelerador, replicado sin restricciones

El tiempo de rearranque se registra **una única vez** (primer rearranque confirmado); las activaciones posteriores no lo modifican. El tiempo de failsafe también se registra una única vez.

**Failsafe post-rearranque.** Si la consulta retorna `0` → acelerador inicial al ESC, y se persiste el failsafe solo la primera vez. El dispositivo sigue sensando. Si la señal regresa por encima del umbral inicial, se mantiene el acelerador inicial hasta que el piloto baje por debajo de ese umbral, momento en que recupera el control directo. El ciclo se repite hasta el apagado.

---

## 12. Arquitectura de firmware

### 12.1. Tareas

| Tarea | Prioridad | Función |
|---|---|---|
| Acelerador | Alta | Consume tramas RMT, valida, publica mediana, replica al ESC, evalúa umbrales |
| Presión | Media | Cosecha el sensor, valida, publica con timestamp, detecta corte por altura |
| Indicadores | Baja | Genera los patrones de LED y buzzer |

El callback de RMT corre en contexto de interrupción, en IRAM: encola la trama y relanza la recepción. No bloquea.

Las esperas son bloqueos de FreeRTOS —la tarea se suspende y el planificador cede la CPU—, no espera activa.

### 12.2. Modelo de adquisición

Cada productor publica `{valor, timestamp, válido}`. Cada consumidor verifica la antigüedad contra su presupuesto de frescura y obtiene el valor o el centinela `0`.

*Esto reemplaza el esquema de "función con presupuesto y reintentos internos" del diseño AVR, que existía porque en un bucle único una lectura lenta bloqueaba todo el sistema. Con tareas independientes ese riesgo no existe, y el presupuesto pasa a ser un criterio de frescura, que es lo que realmente importa.*

### 12.3. Fuente de tiempo

El temporizador de sistema, derivado del reloj principal y por lo tanto del cristal externo. **No usar nada apoyado en el oscilador RC interno.**

Con 10 ppm, el error sobre 30 s es de 0,3 ms. El retardo dominante es la detección del arranque: hasta un frame (25 ms). Ambos muy dentro de los 0,1 s del EDIC.

### 12.4. Configuración del proyecto

Todo viaja en el binario; la placa no se modifica físicamente.

| Opción | Valor | Motivo |
|---|---|---|
| `CONFIG_BOOTLOADER_LOG_LEVEL` | Mínimo | Reduce el tiempo de arranque |
| `CONFIG_LOG_DEFAULT_LEVEL` | Mínimo | Ídem |
| `CONFIG_ESPTOOLPY_FLASHMODE` | QIO | Casi duplica la velocidad de carga desde flash |
| `CONFIG_ESP32C3_RTC_CLK_CAL_CYCLES` | 0 | Omite la calibración del reloj lento |
| `CONFIG_BOOTLOADER_SKIP_VALIDATE_ON_POWER_ON` | **NO usar** | Ahorra tiempo pero omite la verificación de integridad del firmware, que es parte de lo que se homologa |

---

## 13. Limitaciones conocidas

### 13.1. Presupuesto de arranque

Los 2 s de EDIC 2.5 b) se cuentan desde la aplicación de alimentación, no desde que corre el firmware. El arranque del C3 —bootloader de ROM, bootloader de segunda etapa, verificación de imagen, inicialización— consume parte de ese presupuesto.

Con la configuración de §12.4, hay un caso reportado en ESP32-C3 de ~96 ms de arranque total. Contra los 1200 ms de la referencia de altura, quedan unos 700 ms de margen.

**Sin esa configuración el arranque puede consumir el presupuesto entero.**

### 13.2. Validez de la presión de piso ante cambios atmosféricos

La presión de piso se mide una única vez; su validez se degrada con el tiempo. El timeout configurable obliga al piloto a reiniciar si no arranca dentro del plazo.

### 13.3. Unicidad del número de serie

La unicidad del hash no está garantizada matemáticamente y el fabricante no garantiza coeficientes de calibración únicos. En la práctica, sobre más de 1000 sensores no se registraron colisiones. En caso de colisión, descartar y reemplazar el sensor.

### 13.4. Tasa de muestreo ante falla del bus I2C

Ante una falla generalizada y reiterada del bus podría no sostenerse la tasa mínima de 10 muestras/s del EDIC. En condiciones normales la tasa supera ampliamente el mínimo.

El driver de I2C del C3 devuelve `ESP_ERR_TIMEOUT` ante bus ocupado o falla de hardware; el timeout es un argumento de la llamada. Dispone además de `glitch_ignore_cnt`, filtro de hardware sobre las líneas, aplicable al ruido del brushless. Si el bus queda trabado, la recuperación manual es pulsos de reloj hasta liberar SDA, condición de stop, y reinicialización del driver.

### 13.5. Resolución de la salida PWM

1,22 µs por paso, contra 0,5 µs del hardware AVR anterior. Sin consecuencia funcional: el ESC no distingue esa diferencia.

---

## 14. Puntos abiertos

### 14.1. Ventana de detección de pico

La ventana de 10 s posterior al corte proviene de la práctica de la categoría, no del texto de la Sección 7. Conviene consultarlo al EDIC antes de presentar a homologación, porque define qué altura se registra.

### 14.2. Recálculo de presupuestos de tiempo

Los siguientes valores están heredados de la plataforma AVR con la biblioteca `Wire` y deben recalcularse con mediciones sobre C3:

- Intervalo mínimo entre muestras de piso (40 ms)
- Timeout de transacción I2C (10 ms)
- Frescura de presión (100 ms)

### 14.3. Tratamiento del reinicio anómalo

`esp_reset_reason()` distingue encendido limpio de brownout, watchdog de tareas, watchdog de interrupciones y pánico.

Un reinicio en vuelo haría que el dispositivo tome referencia de altura cero en el aire y rehabilite el motor. El hardware de §4.3 cubre la causa de alimentación; falta definir el tratamiento de las causas de software.

Opción planteada, pendiente de elaborar: bloqueo terminal ante cualquier causa distinta de encendido limpio, con patrón de indicación propio y registro en NVS.

---

## 15. Sin verificar

Lo siguiente sostiene decisiones de esta especificación y **no fue confirmado**:

| Ítem | Impacto si no se cumple |
|---|---|
| Tasa efectiva del BMP280 con ×8 y standby mínimo | Si no supera 10 Hz con margen, revisar oversampling y presupuesto de ruido |
| Tiempo de arranque real en la placa concreta | Si excede ~800 ms, acortar la ventana de presión de piso |
| Límite de entrada del LDO de la Super Mini | Variantes con ME6211 rondan 6 V; el BEC entrega 5,5 V |
| Si el driver de RMT del C3 ubica su ISR en IRAM por defecto | Determina el trabajo de §10.3 |
| Deriva térmica del BMP280 montado en el pod | Estimada en ~25 cm sobre un presupuesto de 2 m |

Ninguno invalida la elección de plataforma. Son puestas a punto.

---

## 16. Prompt de generación de código

*Genera TODO el proyecto siguiendo esta especificación al pie de la letra y con el código más eficiente posible para el hardware definido.*

*Fuente de verdad: esta especificación y este prompt mandan siempre. Si te entrego un proyecto de referencia, úsalo solo como guía; ante cualquier diferencia, gana la especificación y el prompt. Los valores por defecto son los de las tablas de la sección 3. Esta especificación es autosuficiente: el algoritmo de número de serie (5.1) incluye constantes, convenciones aritméticas y vectores de prueba verificados, por lo que no necesitás código de referencia para reproducirlo.*

*NO portes código del proyecto AVR anterior. La funcionalidad es la misma; la implementación debe aprovechar el hardware nuevo. Cualquier patrón que exista solo por limitaciones del ATmega328P debe descartarse.*

*El código de referencia NO es modelo de estilo. Aunque use retornos tempranos u otros patrones, no los imites: el estilo lo define este prompt.*

*Antes de empezar, hacé TODAS las preguntas que tengas. Una vez que arrancás, no preguntes más: ante una ambigüedad menor tomá la interpretación más fiel a la especificación y documentá el supuesto como comentario en el código.*

*Antes de escribir el primer archivo, analizá el sistema completo, identificá los datos que se producen y consumen entre módulos, y documentá las decisiones de optimización. Luego, para cada archivo: (1) citá los puntos de la especificación que cubre, (2) verificá que no haya redundancias, (3) escribí el código, (4) verificá que cada garantía esté implementada y que no haya operaciones redundantes. Todo ese análisis va como comentarios en el código, no en el chat.*

*Plataforma: ESP-IDF nativo sobre ESP32-C3 Super Mini. No uses el framework Arduino ni bibliotecas de terceros para el sensor: el driver del BMP280 se implementa según el procedimiento de compensación de la hoja de datos de Bosch.*

*El sensor es exclusivamente BMP280, en 0x76 o 0x77. Validá el Chip ID (registro 0xD0 = 0x58).*

*Marcá con IRAM_ATTR el callback de RMT y todo lo que invoque; usá DRAM_ATTR en los datos constantes que ese camino toque. Asigná la interrupción con ESP_INTR_FLAG_IRAM. Dejá un comentario explicando por qué.*

*Usá float de 32 bits, nunca double: el ESP32-C3 no tiene FPU.*

*La versión del proyecto es la 14.0; el nombre del proyecto debe contenerla y debe verse reflejada internamente donde corresponda.*

*Estructura: cada etapa operativa en su propio módulo; las funciones comunes se agrupan por afinidad funcional. La lectura de acelerador es conceptualmente distinta de la salida de acelerador: no tienen afinidad entre sí. No uses #define ni directivas de compilador para valores de configuración; usá constantes.*

*Estilo OBLIGATORIO: programación estructurada en todo el código — un solo punto de salida por función, sin retornos tempranos, control de flujo solo con secuencia, selección e iteración. Únicas excepciones: las ISR y los callbacks del driver. Verificá función por función antes de entregar.*

*Conceptos a respetar sin reinterpretar: pulso y frame son magnitudes distintas con su propio rango; un pulso pertenece a un frame por compartir el flanco de subida inicial. Los umbrales de acelerador (inicial, de arranque, de apagado) no son intercambiables. Las funciones de adquisición devuelven 0 ante fallo y la política ante ese 0 es por etapa (sección 11). Filtrar por rechazo de transitorios está permitido; suavizar o promediar la presión está prohibido.*

*Comentarios en español.*

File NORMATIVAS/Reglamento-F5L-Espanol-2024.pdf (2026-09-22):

CATEGORÍA PLANEADORES R/C

CLASE F5L – PLANEADORES TÉRMICOS R.E.S. CONTROLADOS POR RADIO CON MOTOR ELÉCTRICO Y AMRT

FECHA DE VIGENCIA: 01/01/2024

### 5.5.12.1 Reglas generales

F5L es una clase para planeadores de 2 ejes controlados por radio con un motor eléctrico y un dispositivo AMRT (ALTIMETER/MOTOR RUN TIMER).
La clase F5L es similar a la F3L y solo se diferencia por el procedimiento de arranque con un motor eléctrico en lugar de goma elástica (bungee). Los modelos cuentan con una envergadura máxima de dos (2) metros, son principalmente de construcción de madera y están controlados por timón, elevador y spoiler(es). Para el lanzamiento, el motor eléctrico puede funcionar durante 30 seg. Debido a las restricciones de construcción y equipamiento, es posible participar en competiciones a un bajo coste y con habilidades medias. Un aspecto clave de esta clase es motivar a jóvenes modelistas e integrarlos al deporte. Las reglas que siguen deben ser entendidas e interpretadas teniendo esto en mente.

5.5.12.2 Definición de un planeador controlado por radio.

Un modelo de aeronave cuya sustentación es generada por fuerzas aerodinámicas que actúan sobre superficies que permanecen fijas. En la clase F5L, el motor eléctrico sirve solo para el lanzamiento. El participante debe controlar el modelo desde el suelo mediante radiocontrol.

5.5.12.3 Especificaciones del modelo para planeadores térmicos F5L controlados por radio.

Un modelo generalmente consta de alas, fuselaje y cola. Los modelos de alas voladoras que no tengan fuselaje y timón o estabilizador vertical o ninguno de estos componentes también están permitidos si tienen solo dos (2) superficies de control. Cada una de estas superficies tiene que ser accionada por un solo servo. En caso contrario, se aplican las reglas de construcción para modelos convencionales aquí descritas.

### 5.5.12.3.1 El modelo está construido principalmente con piezas de madera. Se permiten los

siguientes métodos:

a) Alas construidas con costillas, abiertas o recubiertas de madera, “D-box”, alas de madera maciza o una combinación de madera maciza y costillas.
b) Todas las piezas deben ser de madera, excepto el borde de ataque, el/los largueros, las piezas de conexión de las semialas y la estructura de la bancada del motor, que pueden ser de fibra de vidrio/carbono o similar.
c) La superficie de las alas podrá estar cubierta por film, seda, papel o tela de poliéster. Las especificaciones a) b) c) son aplicables también a los planos de cola.
d) El espacio entre el borde trasero de los spoilers y el borde de salida debe ser de al menos 5 cms. Uno o dos servos pueden activar los spoilers.
e) El fuselaje debe ser enteramente de madera o con la parte trasera de tubo de fibra de vidrio/carbono (GRP/CFRP) o perfil de Kevlar. El tubo/perfil no debe extenderse por la mitad delantera del área del ala.
f) La superficie de madera del fuselaje puede estar cubierta con fibra de vidrio/carbono (GRP/CFRP) o Kevlar, pero no más de un máximo de 1/3 del área total. La superficie se puede proteger con barniz o similar descrito en c).
g) Las bisagras y las superficies de control están exentas de la restricción GRP/CFRP.
h) La elección del motor eléctrico es libre.

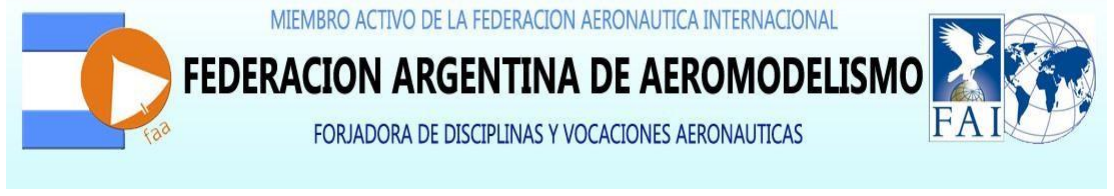
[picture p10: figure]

i) La selección de batería es libre.

### 5.5.12.3.2 No está permitido el uso de:

a) Moldes positivos o negativos para la construcción del fuselaje, alas o el tratamiento de las superficies.
b) Un dispositivo de freno fijo o retráctil (es decir, perno, protuberancia en forma de diente de sierra, etc.) para reducir la velocidad del modelo en el suelo durante el aterrizaje. La parte inferior del modelo no debe tener protuberancias.
c) Un morro de fuselaje con un radio inferior a 5 mm.
d) Lastre no instalado internamente y sujeto de manera segura dentro del fuselaje.
e) Cualquier telemetría, excepto la intensidad de la señal de radio, la temperatura del receptor y el voltaje de la batería. No se permite variómetro.
f) Cualquier telecomunicación entre el competidor y los ayudantes, incluidos teléfonos móviles o walkie-talkies.

### 5.5.12.4 Descripción de la competición:

a) En la competición, se realizarán por lo menos cuatro (4) rondas clasificatorias. Para cada ronda de clasificación, los participantes se dividirán en grupos de vuelo. Los resultados de cada grupo de vuelo se normalizarán para llegar a puntuaciones semejantes entre los grupos de vuelo. A la puntuación más alta dentro de cada grupo de vuelo se le asignarán 1000 puntos, y las puntuaciones restantes dentro de ese grupo serán proporcionales a la puntuación de vuelo sin procesar (“en bruto”) de cada participante en relación con la mejor puntuación de vuelo sin procesar dentro de ese grupo. El tamaño del grupo en el “Fly-Off” será el mismo que en las rondas preliminares. Los participantes que vuelen con los puntos totales más altos de la ronda preliminar competirán en un "desempate" (mínimo 2 rondas) para determinar la clasificación final.
b) El competidor podrá utilizar tres (3) modelos en el concurso. El competidor puede cambiar de modelo en cualquier momento, pero dentro de una ronda solo si el modelo utilizado primero se coloca dentro de un radio de 15 metros del lugar de aterrizaje asignado.
c) El competidor podrá utilizar hasta dos (2) ayudantes. Estos lo ayudan a lanzar y recuperar el modelo, informándole de las condiciones climáticas y el tiempo de vuelo y gestionando el inicio.
d) El organizador debe tener anotadores/cronometradores oficiales disponibles. Si este no es el caso, el ayudante del piloto controlará el tiempo y el organizador tomará muestras de los tiempos de vuelo con regularidad. Las desviaciones de más de tres (3) segundos a favor del participante darán lugar a un vuelo con cero puntos.

### 5.5.12.5 El campo de vuelo:

a) La competición debe llevarse a cabo en un sitio que tenga un terreno razonablemente nivelado, lo que minimizará la posibilidad de que se produzcan ascendencias por ladera.
b) Debe haber puntos de inicio/aterrizajes marcados para cada competidor con una separación mínima de ocho (8) metros. El despegue debe ocurrir dentro de los dos (2) metros del punto de inicio/aterrizaje asignado. Esta regla también se aplica en los reinicios.
c) La distancia entre el morro del fuselaje y el punto de aterrizaje se medirá con una cinta o cuerda, que podrá fijarse en el punto de aterrizaje.
d) El director del concurso determinará los límites de aterrizaje. Aterrizar fuera de los límites dará como resultado una puntuación de cero para ese vuelo. (ver también 8.2).

### 5.5.12.6 Interrupciones:

a) El director del concurso puede interrumpir la competición y reiniciar los puntos de salida/aterrizaje.
b) El concurso será interrumpido por el director del concurso si las condiciones climáticas para los modelos ya no son razonables.

### 5.5.12.7 Lanzamiento:

El inicio es después del comienzo del tiempo de trabajo con el motor eléctrico en marcha. Para los diseños que no permiten un arranque seguro con el motor en marcha (por ejemplo, aviones con motor montado en la parte trasera de las alas), el motor se enciende tan pronto como sea posible después del lanzamiento, y el tiempo comienza cuando el motor se pone en marcha.
El tiempo de funcionamiento del motor (30 segundos) y la altura inicial (90 m) están limitados por un dispositivo aprobado por EDIC-WG (ELECTRONIC DEVICES IN COMPETITIONS WORKING GROUP) -por ejemplo, el Altis V4, Altis V4+, Altis Micro, Altis Nano, etc. El organizador debe verificar la configuración del AMRT antes de la competencia. El organizador puede consultar el AMRT en cualquier momento después de un vuelo. El vuelo se registra como una puntuación de cero si los ajustes difieren de los preestablecidos.

Requisitos para el AMRT:

a) Tiempo y altitud de apagado.
b) Sin telemetría durante el vuelo competitivo.
c) Ningún cambio en los valores de ajuste a través del transmisor.
d) Almacenamiento del (último) vuelo con punto de encendido y apagado (altura y tiempo) del motor eléctrico.
e) Posibilidad de verificación después de un vuelo.

### 5.5.12.8 Vuelos de Concurso

a) El competidor tiene derecho a por lo menos cuatro (4) vuelos oficiales.
b) El concursante tiene derecho a intentos ilimitados durante el tiempo de trabajo. Antes de reiniciar el vuelo, la batería debe desconectarse brevemente del controlador para reiniciar el AMRT.
c) Un intento oficial comienza cuando el modelo deja la mano del competidor o su ayudante con el motor eléctrico en marcha.
d) En caso de intentos múltiples, el resultado del último vuelo será la puntuación oficial.

5.5.12.9 Repetición de vuelos.

El competidor tiene derecho a un nuevo tiempo de trabajo si:
a) Su modelo en vuelo o en proceso de lanzamiento choca con otro modelo en vuelo o en proceso de lanzamiento.
b) Cuando su vuelo se ve obstaculizado o abortado por un hecho ajeno a su voluntad. Para reclamar un nuevo vuelo teniendo en cuenta las condiciones mencionadas anteriormente, el competidor debe asegurarse de que los cronometradores oficiales hayan anotado las condiciones adversas y aterrizar su modelo lo antes posible después de este evento.
Tenga en cuenta que si el competidor continúa despegando o volando después de las condiciones adversas que afectan su vuelo o vuelve a despegar después de superar las condiciones adversas, se considera que ha renunciado a su derecho a un nuevo tiempo de trabajo.

### 5.5.12.10 Aterrizaje

a) A cada competidor se le asignará un lugar de inicio/aterrizaje antes de cada vuelo. El competidor será responsable de usar el lugar de aterrizaje asignado correcto.

b) Durante el proceso de aterrizaje, solo el piloto y su ayudante pueden estar a menos de 10 metros del lugar de aterrizaje. Cualquier otro ayudante y cronometrador se mantendrá a distancia.
c) Después del aterrizaje, los competidores pueden recuperar su modelo de aeronave antes del final de su tiempo de trabajo, siempre que no obstaculicen a otros competidores o modelos de aeronaves en su grupo. Un modelo así recuperado puede ser relanzado durante el tiempo de trabajo. No se puede registrar ninguna puntuación de aterrizaje para un modelo tocado antes de medir la distancia en el aterrizaje.

### 5.5.12.11 Puntuación

La puntuación de vuelo sin procesar para cada ronda consiste en la puntuación del tiempo de vuelo y los puntos de bonificación de aterrizaje.

### 5.5.12.11.1 Puntuación del tiempo de vuelo

El intento se cronometrará desde el momento en que se suelta de la mano el modelo arrancado hasta que: El modelo de aeronave toque el suelo por primera vez; o
a) Finalización del tiempo de trabajo del grupo.
El tiempo máximo de vuelo es de 6 minutos y 30 segundos (390s) dentro de los nueve (9) minutos (540s) de tiempo de trabajo. El tiempo de vuelo se registrará en segundos completos. Si el vuelo tiene una duración superior a 6:30 minutos (390s), el tiempo de sobrevuelo se descontará de los 390s. Cada segundo de tiempo de vuelo se puntuará con dos (2) puntos. A la puntuación más alta dentro de cada grupo de vuelo se le asignarán 1000 puntos, y las puntuaciones restantes dentro de ese grupo serán proporcionales a la puntuación de vuelo sin procesar de cada participante en relación con la mejor puntuación de vuelo sin procesar dentro de ese grupo.

### 5.5.12.11.2 Puntuación del Aterrizaje

Se otorgará un bono de aterrizaje de acuerdo a la distancia al punto de aterrizaje marcado por los organizadores de acuerdo a la siguiente tabla:

DISTANCIA AL PUNTO DE ATERRIZAJE Y PUNTUACIÓN

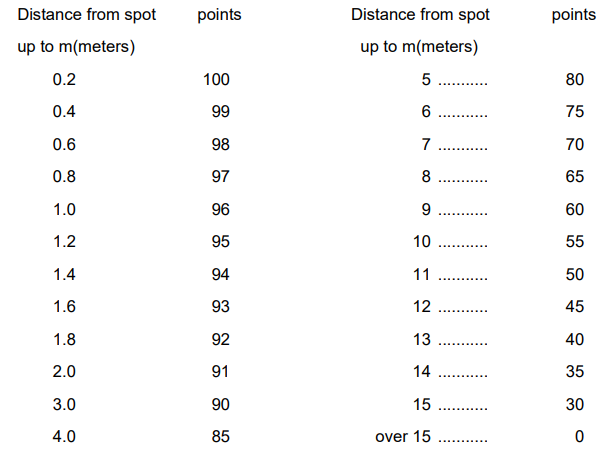
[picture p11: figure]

Se anotarán cero puntos por aterrizaje para el competidor, si:

a) El modelo pierde alguna parte.
b) El modelo no está en condiciones de aeronavegabilidad después del aterrizaje. Si hay alguna duda al respecto, se debe demostrar la aeronavegabilidad.
c) El modelo está sobrepasando el tiempo de trabajo del grupo.
d) El modelo tocó al competidor o ayudante durante el aterrizaje.
e) El competidor o ayudante tocó el modelo antes de que el anotador oficial hiciera la medición de la distancia.
Se otorgan cero puntos para la tarea completa (vuelo y aterrizaje) si:
a) El modelo aterriza fuera del área de aterrizaje definida por el organizador. Dentro del tiempo de trabajo, el competidor puede realizar otro intento.
b) El modelo está sobrepasando el tiempo de trabajo por más de 30 segundos.

### 5.5.12.12 Clasificación final

Si se vuelan cinco (5) o menos rondas clasificatorias, la puntuación total lograda por el competidor será la suma de sus puntuaciones para todas las rondas voladas.
Si se vuelan más de cinco (5) rondas, su puntuación más baja se descartará antes de determinar su puntuación total. Para los competidores que calificaron para el desempate, la clasificación final está determinada por la clasificación en el desempate; para otros competidores, la clasificación se realiza mediante la clasificación en las rondas de clasificación.

### 5.5.12.13 Información Adicional

El Boletín Informativo indicará cualquier modificación de las limitaciones del espacio aéreo.

RESUMEN

Modelo de 2m máximo de envergadura, de dos ejes (dirección y profundidad), más spoiler (opcional) Construcción en madera (con alguna parte en carbono)
Motor y batería libre
No se permite telemetría (por ejemplo variómetro) que se controle desde la emisora.
Competición de un mínimo de 4 rondas.
Tiempo de duración máxima del motor 30 segundos o 90m de altitud (lo que antes suceda) controlados por un dispositivo AMRT.
Tiempo máximo de vuelo 6’ 30’’ (390 segundos), dentro de un tiempo de trabajo de 9’ (540 segundos)

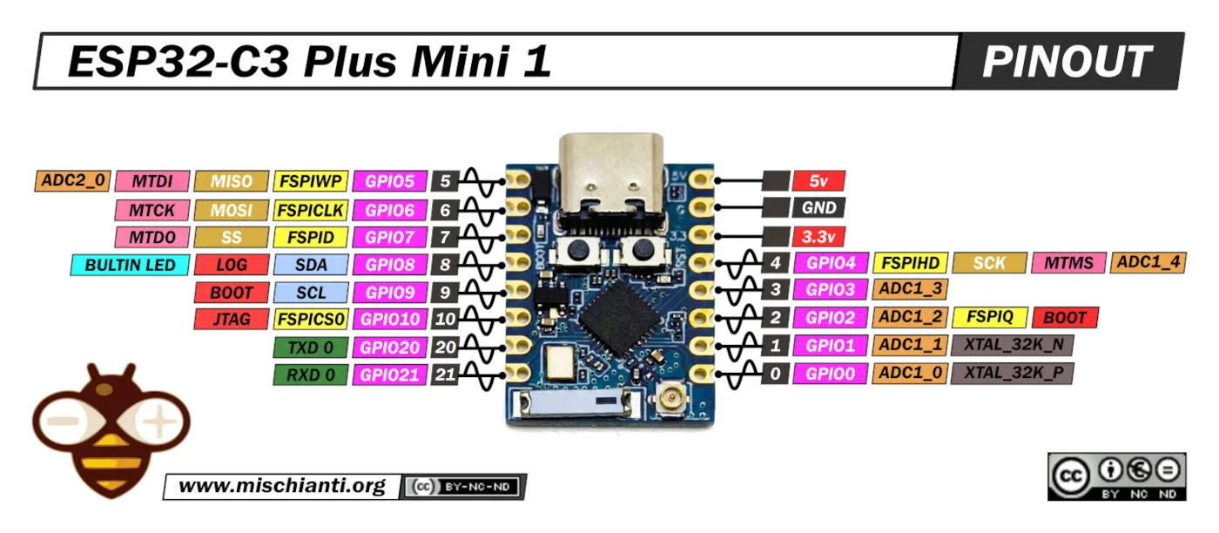
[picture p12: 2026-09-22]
IMAGENES/ESP32C3 pinout.png

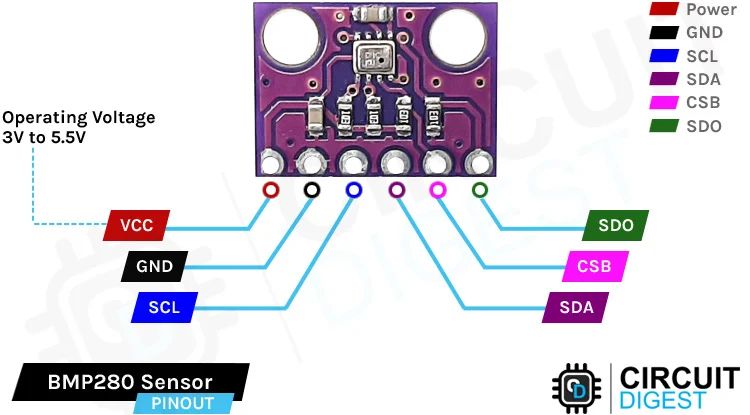
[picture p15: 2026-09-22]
IMAGENES/BMP280.jpg

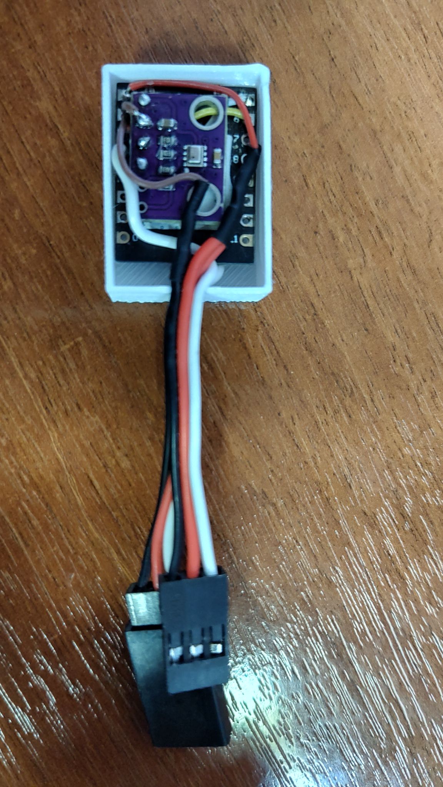
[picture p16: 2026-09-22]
IMAGENES/CASE_Indor.jpg

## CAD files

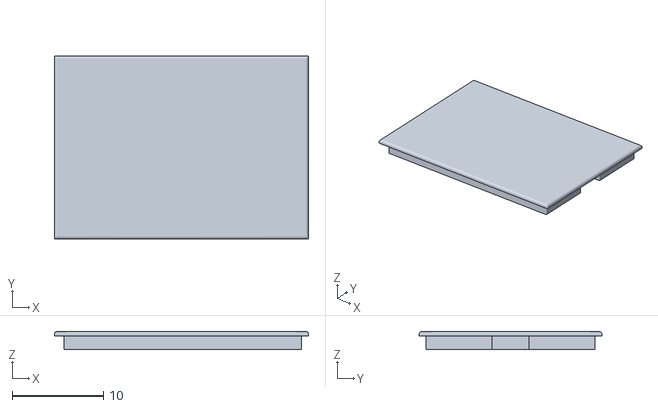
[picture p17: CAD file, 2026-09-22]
CARCASAS/STL/CASE_SIN_LCD_TAPA.stl
27.8 x 20.0 x 2.00

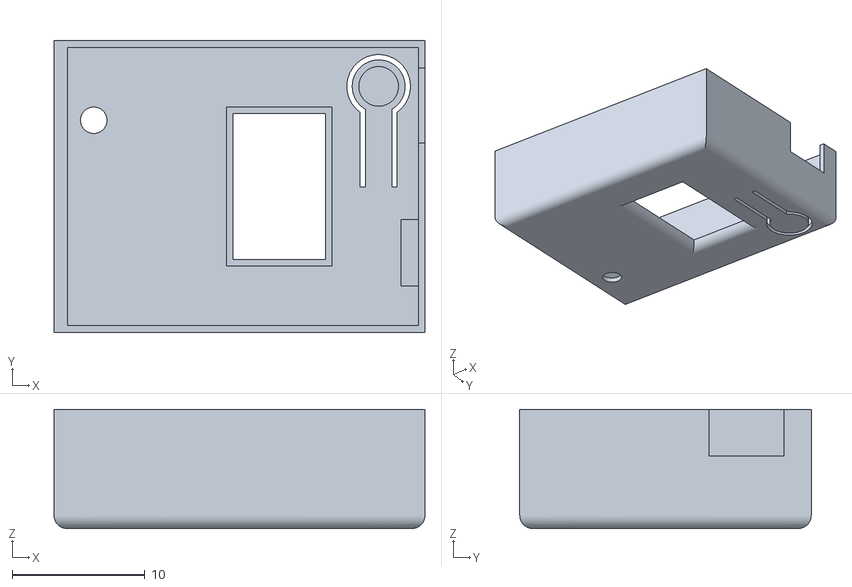
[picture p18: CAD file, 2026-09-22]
CARCASAS/STL/CASE_OLED_BASE.stl
28.0 x 22.0 x 9.00

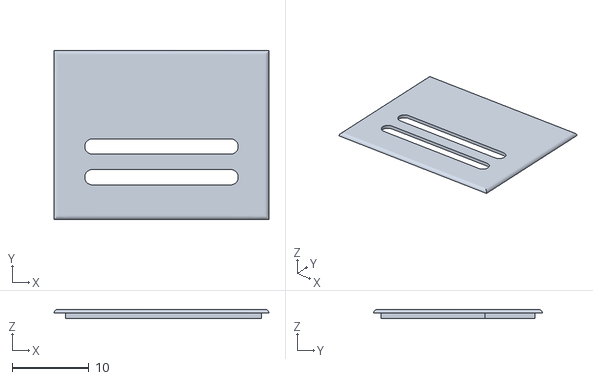
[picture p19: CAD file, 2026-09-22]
CARCASAS/STL/CASE_OLED_TAPA.stl
28.0 x 22.0 x 1.20

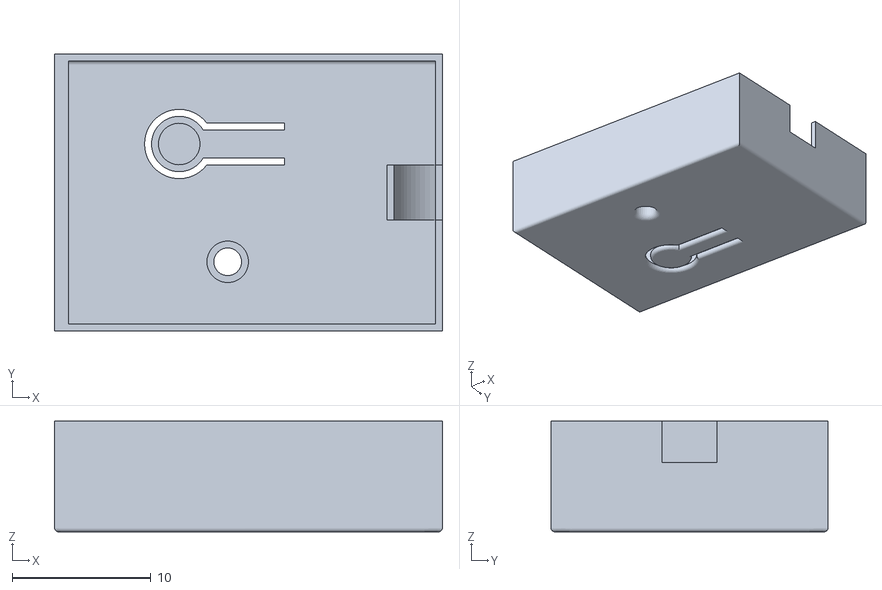
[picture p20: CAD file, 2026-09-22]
CARCASAS/STL/CASE_SIN_LCD_BASE.stl
28.0 x 20.0 x 8.00

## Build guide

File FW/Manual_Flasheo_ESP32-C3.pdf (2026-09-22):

# INDICE

Manual de flasheo - ESP32-C3

Seccion | Pagina
Paso 1 - Configuracion inicial | 2
Paso 2 - Seleccion de los archivos BIN | 2
Paso 3 - Puerto COM y velocidad | 3
Paso 4 - Poner la placa en modo de descarga | 3
Paso 5 - Finalizacion y comprobacion | 3
Importante - Seguridad | 4
Actualizacion de una placa ya en funcionamiento | 5
Paso 6 - Web Control y configuracion por Bluetooth | 6
Manual de flasheo ESP32-C3 | Pagina 1

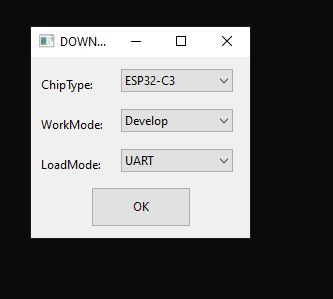
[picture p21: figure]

Manual de flasheo ESP32-C3 | Pagina 1

# Manual de flasheo - ESP32-C3

Este procedimiento permite cargar el firmware en la placa ESP32-C3 utilizando ESP Flash Download Tool.

## PASO 1 - Configuracion inicial

Al iniciar la herramienta, seleccionar:
ChipType: ESP32-C3
WorkMode: Develop
LoadMode: UART

Configuracion inicial de la herramienta.

## PASO 2 - Seleccion de los archivos BIN

Cargar los tres archivos y asignar exactamente las siguientes direcciones: bootloader.bin -> 0x0
partitions.bin -> 0x8000
firmware.bin -> 0x10000
IMPORTANTE: tildar las casillas de los tres archivos BIN. Ver la imagen con atencion. Si alguno de los archivos queda sin tildar, ese archivo no se grabara en la placa.

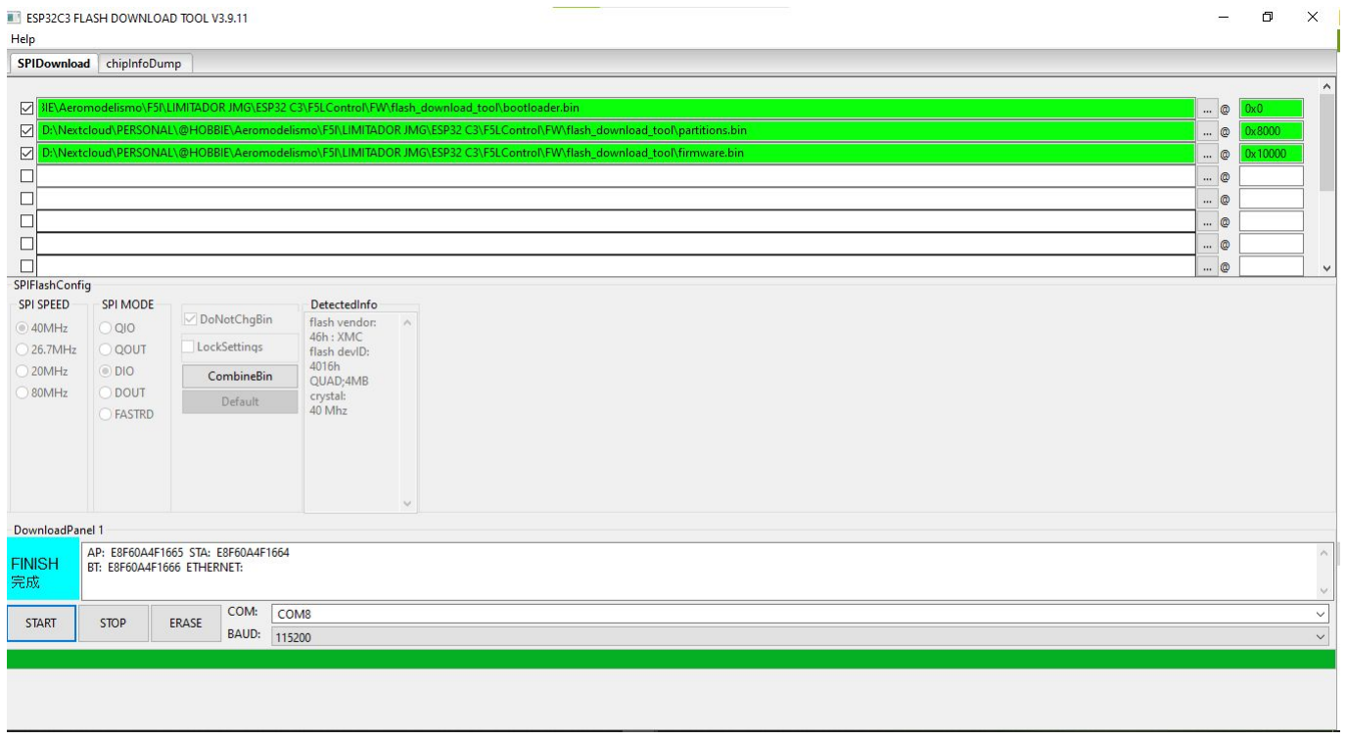
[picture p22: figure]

Los tres BIN deben estar seleccionados y con sus direcciones correctas.

## PASO 3 - Puerto COM y velocidad

Seleccionar el puerto COM correspondiente a la placa. Para este procedimiento se puede utilizar 115200 como velocidad de carga.

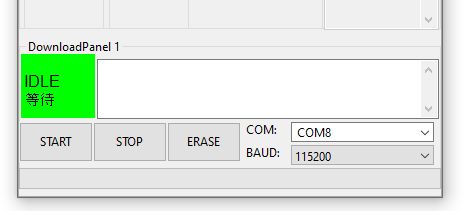
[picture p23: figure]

Ejemplo de seleccion del puerto COM y BAUD 115200.

## PASO 4 - Poner la placa en modo de descarga

Antes de presionar START:
1. Desconectar el cable USB de la placa.
2. Mantener presionado el boton BOOT.
3. Sin soltar BOOT, conectar el cable USB a la computadora.
4. Esperar unos segundos y soltar BOOT.
5. Verificar que aparezca el puerto COM correcto.
6. Presionar START para comenzar el flasheo.

## PASO 5 - Finalizacion y comprobacion

Cuando la herramienta indique FINISH, el firmware fue cargado. Desconectar la placa y volver a conectarla normalmente, sin presionar BOOT.
Si todo esta correcto, el LED azul comenzara a parpadear. Esto indica que el ESP32-C3 inicio y el firmware esta funcionando.

## IMPORTANTE - Seguridad

Para este procedimiento realizar solamente un flasheo normal del firmware.
NO modificar ni utilizar: eFuses, Secure Boot, Flash Encryption ni bloqueos de seguridad permanentes. Estas opciones pueden realizar cambios permanentes en el ESP32-C3 y no son necesarias para cargar este firmware. No quemar eFuses ni activar funciones de seguridad permanente.

## ACTUALIZACION DE UNA PLACA YA EN FUNCIONAMIENTO

Si la placa ESP32-C3 ya esta funcionando y solamente se desea actualizar el firmware, NO es necesario volver a grabar los tres archivos BIN.

Para una actualizacion normal cargar unicamente:

firmware.bin -> 0x10000

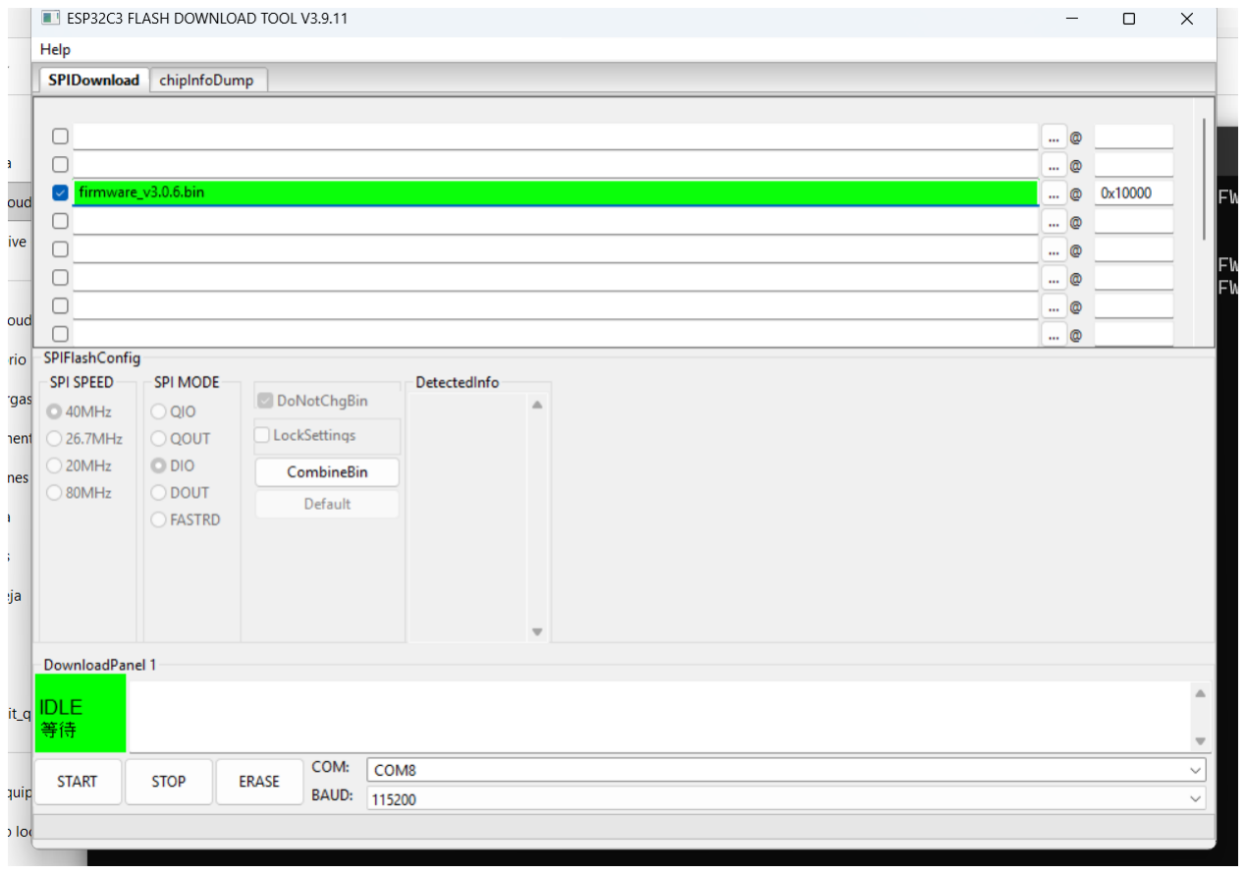
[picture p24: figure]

Ejemplo correcto: solo firmware seleccionado en 0x10000.

### IMPORTANTE - Conservar datos de vuelo y configuraciones

Para evitar sobrescribir las particiones donde se almacenan datos y configuraciones, no cargar ni seleccionar partitions.bin ni bootloader.bin durante una actualizacion de una placa que ya se encuentra configurada y funcionando.

Tampoco utilizar la opcion ERASE. Realizar solamente el flasheo de firmware.bin en la direccion 0x10000 y luego reiniciar la placa normalmente.

ATENCION: El procedimiento completo con bootloader.bin + partitions.bin + firmware.bin se reserva para una instalacion completa, una placa nueva o una reconstruccion completa. Para una simple actualizacion usar solamente firmware.bin.

Manual de flasheo ESP32-C3 | Pagina 5

## PASO 6 - WEB CONTROL Y CONFIGURACION POR BLUETOOTH

Una vez finalizado el flasheo y comprobado que la placa inicia correctamente, descargar WebControl. Esta herramienta permite conectarse a la placa desde el navegador Google Chrome mediante Bluetooth y configurar sus parametros.

WEB CONTROL

1. Descargar el paquete WebControl.
2. Extraer el archivo index.html.
3. Abrir index.html con Google Chrome.
4. Presionar Conectar y seleccionar la placa por Bluetooth.
5. Una vez conectado, realizar la configuracion de los parametros necesarios.

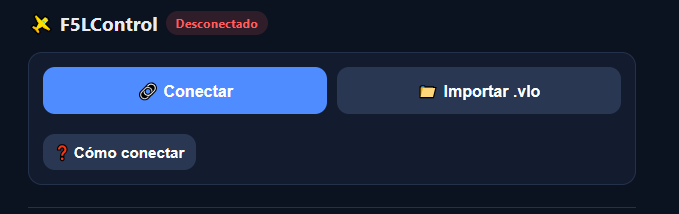
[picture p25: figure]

Pantalla de WebControl: utilizar el boton Conectar para enlazar la placa por Bluetooth.

## IMPORTANTE

La configuracion se realiza desde Google Chrome. El navegador debe tener acceso a Bluetooth y la placa debe estar disponible para el enlace. Si la conexion se realiza correctamente, WebControl mostrara el estado de la placa como conectada.

El boton Importar .vlo se utiliza para cargar archivos de vuelo guardados; no es necesario para realizar la configuracion inicial de la placa.

Manual de flasheo ESP32-C3 | Pagina 6

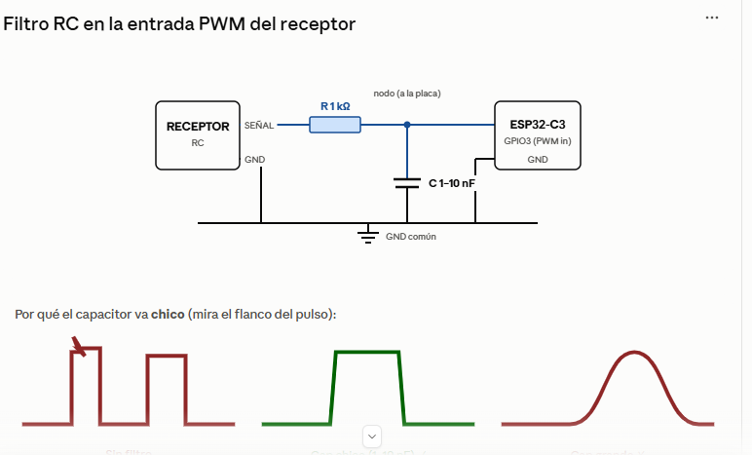
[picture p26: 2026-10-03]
IMAGENES/ARMADO/Filtro Ruido PWM IN.png

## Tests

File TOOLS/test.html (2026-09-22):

# 🛠️ F5LControl · Test Sin conexión

Herramienta de banco: barómetro, PWM del receptor, prueba de ESC y datos del equipo. Vía USB (cable) o Bluetooth.

🔌 Conectar USB 📶 Conectar Bluetooth ✖ Desconectar

🌡️ Barómetro

cada s ▶ Iniciar ⤢ Ver todo ⬇ CSV

Estado–

Sensor–

Temperatura– °C

Presión– hPa

Altura (rel. al encendido)– m

Presión (hPa) Temperatura

📡 PWM del receptor ▶ Iniciar

Señal–

PWM filtrado– µs

Último de la radio– µs

Pulsos consecutivos–

Mínimo calibrado–

⚙️ Prueba de ESCsolo USB

⚠️ SIN HÉLICE. Esta prueba hace girar el motor. Sacá la hélice antes de usarla.

Confirmo que no hay hélice puesta

1000 µs

Enviar al ESC ■ Mínimo (1000)

ℹ️ Datos del equipo

Config Log inicio Memoria

ConsolaMostrar

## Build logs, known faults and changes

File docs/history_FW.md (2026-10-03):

# Historial de cambios — Firmware F5LControl

> Cambios del **firmware**, del más reciente al más antiguo.
>
> **Referencias:** ✨ Mejora · 🔧 Arreglo · 🎨 Visual

| Versión | Tipo | Cambio |
|:---:|:---:|---|
| **3.1.10** | 🎨 | Ajustes de pantalla y botón: **"ARMADO"** se muestra **solo antes de despegar** (una vez que diste motor no reaparece; la pantalla queda apagada hasta el resultado). Y el **reset con el botón** funciona en el piso **aunque la pantalla esté apagada**: se habilita con el **motor apagado** — antes de pasar la altura de aviso siempre, y después de volar solo si ya **bajó** de esa altura (resultado a la vista). Antes quedaba bloqueado tras dar motor. |
| **3.1.9** | 🎨 | Pantallas del OLED más claras: al **armar** muestra **"ARMADO"** en un recuadro (antes "LISTO"); el **reset con el botón** al terminar dice **"GRABADO"** (antes "LISTO", se confundía con la de volar); y la pantalla de **resultado** del vuelo pone el **VÁLIDO/NULO más chico** y el número de **máximo/zoom más grande** (más fácil de leer de lejos). |
| **3.1.8** | 🔧 | Arregla el **E1 aleatorio de la versión con pantalla** (al armar y en vuelo). Causa: el **OLED comparte el bus I²C con el barómetro** y el clon a veces lo **traba** (no suelta la línea), lo que hacía fallar la lectura del sensor. Ahora el firmware **destraba el bus I²C** al arrancar (antes de detectar el baró) y, si una lectura falla en vuelo, **recupera el bus y re-inicializa el sensor** en vez de quedar colgado (sin perder el cero del vuelo). Además baja el bus I²C a **100 kHz** (más tolerante con el OLED clon → se traba menos). La versión **sin pantalla** no estaba afectada. Además, la pantalla de **"listo para volar"** ahora muestra solo la palabra **"LISTO"** (antes mostraba la altura actualizándose cada segundo): más claro y con **menos dibujos al OLED** antes de despegar (ayuda a que el bus no se trabe). |
| **3.1.7** | ✨ | El **PWM mínimo del ESC** (el valor de **reposo/failsafe/arranque** que se le manda al ESC apagado) ahora es **configurable de 900 a 1000 µs** (default **900**). Algunos ESC **no arman** si el mínimo está en 1000; bajándolo a 900 sí lo toman. Se ajusta desde la web en la sección **Avanzadas (Solo para expertos)** con un deslizador. **Aplica al reiniciar.** Probar **SIN hélice**. |
| **3.1.6** | ✨ | **Reset controlado con el botón** (solo versión con pantalla): manteniendo el botón **2 s** (configurable) **con la pantalla encendida** (o sea, en el piso), el equipo **cierra y graba el vuelo**, pone el motor en mínimo y **se reinicia** — sin tener que desconectar la batería. Muestra **"RESET" + barra de progreso** mientras lo mantenés, y **"LISTO"** al cumplirse (soltás y reinicia). Habilitar/tiempo quedan listos para configurar desde la web. |
| **3.1.5** | 🔧 | **Seguridad:** al **resetear** el equipo con la batería puesta, el motor ya **no da un tirón**. Antes, tras el reset, la salida al ESC quedaba ~1 s en un estado indefinido y algunos ESC lo tomaban como acelerador; ahora esa salida se pone en **mínimo/apagado apenas arranca** el firmware. (Recomendado además un pull-down de 10k en la señal del ESC para cubrir el instante previo al firmware.) |
| **3.1.4** | 🔧 | El **corte por sensor** ahora tolera un glitch corto del barómetro: en vez de cortar a las 3 lecturas malas (~150 ms), corta solo si el sensor sigue fallando **~1,5 s seguidos**. Así un bache momentáneo (ruido del motor al arrancar) ya no corta el vuelo, pero un sensor realmente colgado igual corta. |
| **3.1.3** | 🔧 | Tres mejoras de pantalla/registro: (1) la pantalla de **resultado** ahora se maneja **por nivel** — por debajo de la altura de aviso y **sin motor** queda encendida, se apaga solo con motor y **vuelve a encender** al apagarlo (un toque de motor por debajo del umbral ya no la deja apagada). (2) **Reintento de detección del OLED** al arrancar (hasta 3 veces): un glitch del bus I²C al encender ya no deja sin pantalla todo el vuelo. (3) Se elimina la **falsa "pérdida de señal" de ~10 s** que aparecía en el registro después de cada corte (la ventana de protección ahora sigue leyendo el receptor). |
| **3.1.2** | 🔧 | Dos correcciones de seguridad/robustez: (1) tras un **rearranque**, si se perdía y volvía la señal con el acelerador al mínimo, podía darse un **breve impulso de motor**; ahora el filtro se reinicia y la salida sube suave desde el mínimo. (2) El estado de "motor encendido" ahora es **único y con antirrebote**: un bache momentáneo del acelerador ya no prende la pantalla a mitad de corrida ni provoca una escritura a memoria con el motor girando. |
| **3.1.1** | 🎨 | Durante la actualización por Bluetooth, la pantalla muestra **UPDATE** con una **barra de progreso** y el porcentaje recibido. Si la actualización se corta, la pantalla vuelve al estado de Bluetooth. |
| **3.1.0** | ✨ | El equipo ahora puede **actualizar su firmware por Bluetooth** desde la web, sin cable. La actualización se inicia solo a pedido y, si algo falla o se corta, el equipo sigue con el firmware anterior. |
| **3.0.25** | 🔧 | El firmware ocupa bastante menos espacio (alrededor de 400 KB menos): se quitó el Wi-Fi, que no se usaba (el equipo funciona solo con Bluetooth). Sin cambios de funcionamiento. |
| **3.0.24** | ✨ | El cero de altura se vuelve a ajustar solo cada vez que la lectura se aleja del cero (con el equipo quieto, también en Bluetooth), hasta que das motor. Al arrancar el motor el cero queda congelado y desde ahí se mide la altura del vuelo. |
| **3.0.23** | ✨ | Guarda un reporte del último arranque (barómetro, receptor, mínimo, memoria y resultado) que se puede consultar desde la web. En los avisos de error, la pantalla muestra además un logo de Bluetooth chico indicando que el equipo quedó accesible por Bluetooth. |
| **3.0.22** | 🎨 | En la pantalla de listo para volar, la altura en metros se actualiza sola cada segundo con la lectura actual del sensor. |
| **3.0.21** | 🔧 | Al encender, el equipo reintenta detectar el sensor de altura antes de dar el aviso de falta de barómetro, para evitar falsos avisos por un fallo momentáneo de conexión o arranque. |
| **3.0.20** | 🎨 | La pantalla de listo para volar muestra la altura en metros (número grande) junto al tilde de OK, y ya no muestra el dato del acelerador. |
| **3.0.19** | ✨ | La altura a la que la pantalla se enciende sola al aterrizar ahora llega hasta 10 metros y viene configurada en 10 metros por defecto. |
| **3.0.18** | 🔧 | Al encender, el cero de altura se calcula de forma más robusta para que el equipo parta lo más cerca posible de 0 m y no muestre desvíos de varios metros estando quieto. El equipo sigue quedando listo para vuelo en 2 segundos. |
| **3.0.17** | 🔧 | La pantalla de resultado ya no queda detenida en un dato al aterrizar (alterna siempre la altura máxima y la altura adicional). La altura de autoencendido predeterminada pasa a 3 m, y una vez activada la pantalla solo se apaga al volver a encender el motor. |
| **3.0.16** | ✨ | Se agregó compatibilidad con un nuevo sensor de altura (BME280). |
| **3.0.15** | 🎨 | La pantalla de Bluetooth muestra el nombre del equipo. |
| **3.0.14** | ✨ | Se mejoró el ingreso al modo Bluetooth y se agregaron avisos en pantalla cuando el equipo no puede iniciar el vuelo. |
| **3.0.13** | 🎨 | Al finalizar el vuelo, la pantalla muestra la altura máxima y la altura adicional ganada tras el corte del motor. |
| **3.0.12** | 🔧 | Se corrigió que la pantalla quedara congelada al reiniciar el equipo. |
| **3.0.11** | ✨ | Se optimizó el guardado de datos para cuidar la memoria del equipo. |
| **3.0.10** | 🔧 | Se corrigió la pérdida de datos en vuelos prolongados. |
| **3.0.9** | 🔧 | La altura máxima de la pantalla coincide con la de la aplicación web. |
| **3.0.8** | 🔧 | Se solucionó el inicio del equipo en placas con pantalla. |
| **3.0.7** | 🔧 | Primer arreglo del inicio con pantalla (mejorado en la 3.0.8). |
| **3.0.6** | ✨ | El vuelo se guarda al confirmarse el despegue, conservando los segundos previos. |
| **3.0.5** | ✨ | Guardado de vuelos orientado a cuidar la memoria (revisado en la 3.0.10). |
| **3.0.4** | 🔧 | Recuperación automática de la memoria dañada para poder volar. |
| **3.0.3** | ✨ | Calibración del acelerador más compatible. |
| **3.0.2** | 🎨 | La aplicación web puede ver el estado del receptor. |
| **3.0.1** | 🎨 | Nuevas pantallas de estado y de resultado del vuelo. |
| **3.0** | ✨ | Soporte inicial para pantalla. |
| **2.6.20** | 🔧 | Respuesta más segura ante la pérdida de señal del receptor. |
| **2.6.19** | 🔧 | Registro de vuelos más robusto. |
| **2.6.18** | ✨ | Respuesta más rápida del control. |
| **2.6.17** | 🔧 | Corrección de la lectura de señal en dos pines de entrada. |
| **2.6.16** | 🔧 | Inicio más confiable con el sensor de altura. |
| **2.6.15** | ✨ | Más pines disponibles para las conexiones. |
| **2.6.14** | ✨ | Compatibilidad con nuevos sensores de altura. |
| **2.6.13** | ✨ | Inicio del equipo más rápido (2 segundos). |
| **2.6.12** | ✨ | La descarga incluye el motivo del corte del motor. |
| **2.6.11** | ✨ | La configuración de diagnóstico queda guardada. |
| **2.6.10** | 🔧 | El motor ya no funciona entrecortado durante el registro. |
| **2.6.9** | 🔧 | Corrección del formateo de la memoria. |
| **2.6.8** | ✨ | Altura de referencia más estable al encender. |
| **2.6.7** | ✨ | Lecturas de altura más estables. |
| **2.6.6** | 🎨 | Indicaciones más claras con el LED durante el vuelo. |
| **2.6.5** | 🔧 | Corrección de la calibración del acelerador. |
| **2.6.4** | 🔧 | Corrección de la lectura de la señal del receptor. |
| **2.6.3** | 🔧 | Corrección de la señal de salida hacia el motor. |
| **2.5** | ✨ | Límites de la categoría fijos y monitoreo por Bluetooth. |
| **2.4** | ✨ | Registro de vuelos en la memoria. |
| **2.3** | ✨ | Lógica completa de corte del motor. |
| **2.2** | ✨ | Control de la salida hacia el motor. |
| **2.1** | ✨ | Lectura de la señal del receptor. |
| **2.0** | ✨ | Estructura inicial del firmware. |

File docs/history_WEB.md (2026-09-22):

# Historial de cambios — Web F5LControl

> Cambios de la **aplicación web**, del más reciente al más antiguo.
>
> **Referencias:** ✨ Mejora · 🔧 Arreglo · 🎨 Visual

| Versión | Tipo | Cambio |
|:---:|:---:|---|
| **3.1.14** | 🔧 | **Detección de aterrizaje más robusta:** ahora calcula el aterrizaje aunque el **barómetro tenga ruido cerca del piso** o el modelo se **levante/mueva justo después de tocar**. Antes esos vuelos quedaban en **"baja confianza"** sin tiempo de vuelo. Usa un "piso robusto" (percentil) que ignora un pozo/deriva transitorios y tolera más variación cerca del suelo. Sigue **conservadora**: un vuelo cortado arriba (sin descenso a piso) no inventa aterrizaje. |
| **3.1.13** | ✨ | En **Avanzadas (Solo para expertos)** se agregó un deslizador para ajustar el **PWM mínimo del ESC** (900 a 1000 µs). Es lo que se manda al ESC en reposo/failsafe; si tu ESC no arma con el mínimo en 1000, bajalo a 900. Requiere firmware **3.1.7+**. Probar **SIN hélice**. |
| **3.1.12** | ✨ | En la sección **Pantalla** se puede **habilitar/deshabilitar el "reset con el botón"** y ajustar el **tiempo de mantener** (1 a 5 s). Requiere firmware 3.1.6+. |
| **3.1.11** | 🔧 | **Detección de aterrizaje** más robusta: ahora también detecta el aterrizaje cuando la grabación **se corta justo al tocar** (el avión bajó y el registro termina abajo, sin unos segundos quieto en el piso). Antes esos vuelos quedaban sin aterrizaje y sin tiempo de vuelo. |
| **3.1.10** | ✨ | En "Buscar actualizaciones", cada bloque (Web y firmware) muestra su descripción y **el botón de actualizar aparece solo si hay una versión nueva**. Al **cerrar** el cartel del OTA, el equipo **se reinicia** para arrancar con el firmware nuevo. |
| **3.1.9** | 🎨 | La actualización por Bluetooth ahora muestra un **cartel (pop-up) con la barra de progreso** para **ambas** vías (repositorio y por archivo), con el aviso de **no cerrar ni desconectar**. |
| **3.1.8** | ✨ | Botón **"Descargar app web"**: guarda el `index.html` (con la versión en el nombre) para usarlo sin internet o compartirlo. |
| **3.1.7** | 🔧 | La **barra de progreso** de la actualización por Bluetooth ahora se ve al actualizar **desde "Buscar actualizaciones"** (antes estaba dentro de la sección "Solo para expertos" y quedaba oculta). |
| **3.1.6** | ✨ | "Buscar actualizaciones" ahora reconoce las versiones **BETA**: se muestran con una etiqueta 🧪 y como **opcional**, para que decidas vos si la instalás o no (nunca se baja sola). |
| **3.1.5** | 🎨 | Distintivo **"Actualización por Bluetooth (OTA)"** en el pie de la página, indicando que el proyecto soporta actualización de firmware por Bluetooth. |
| **3.1.4** | 🔧 | "Buscar actualizaciones" y la descarga del firmware ahora se leen desde **GitHub Pages** del repo (más estable) en vez de `raw.githubusercontent`, que a veces daba un error temporal (503). Sigue siendo el mismo repo público. |
| **3.1.3** | 🔧 | El veredicto **válido / nulo** del vuelo ya no se marca como nulo por un **bache momentáneo** del acelerador: un corte se cuenta solo si se sostiene. Un rearranque real (sostenido) se sigue detectando como nulo por reglas F5L. |
| **3.1.2** | 🎨 | La actualización de firmware **por archivo** se movió a la sección "Solo para expertos". La actualización **automática desde el repositorio** sigue en "Buscar actualizaciones". |
| **3.1.1** | ✨ | Cuando hay una versión de firmware **más nueva en el repositorio**, la app la baja sola y la actualiza por Bluetooth con un botón (además del selector manual de archivo). |
| **3.1.0** | ✨ | La app ahora puede **actualizar el firmware del equipo por Bluetooth**: elegís el archivo `firmware.bin`, se envía con barra de progreso y, si algo falla o se corta, el equipo sigue con la versión actual. |
| **3.0.22** | 🎨 | El botón **"Consultar log de inicio"** ahora está dentro del recuadro de "Estado del equipo" (que se muestra al conectar), a la derecha; el resultado aparece justo debajo y se puede ocultar con una ✕. |
| **3.0.21** | 🔧 | Se quitó la **altura sobre el nivel del mar** de "Consultar barómetro": era solo una estimación (dependía de la presión del día) y podía confundir. Se mantiene la altura relativa al encendido. |
| **3.0.20** | ✨ | Nueva sección **"Consultar log de inicio"**: muestra cómo fue el último arranque del equipo (barómetro, receptor, mínimo, memoria y resultado), con marcas de OK/falla. |
| **3.0.19** | ✨ | En "Consultar barómetro" se agrega la **altura sobre el nivel del mar (aproximada)**, además de la altura relativa al encendido. |
| **3.0.18** | ✨ | La altura de autoencendido de la pantalla ahora se puede ajustar hasta 10 metros. |
| **3.0.17** | ✨ | La app ahora está en **español e inglés**: elegís el idioma con el botón 🌐 de arriba (arranca en el del dispositivo y recuerda tu elección). |
| **3.0.16** | 🎨 | Textos más claros en la sección Pantalla. |
| **3.0.15** | ✨ | El aviso de nueva versión indica el tipo de cambio y su importancia. |
| **3.0.14** | 🎨 | En el gráfico, el tiempo comienza en el despegue. |
| **3.0.13** | 🎨 | El gráfico ya no muestra alturas negativas. |
| **3.0.12** | 🔧 | Mejor detección del aterrizaje en vuelos prolongados. |
| **3.0.11** | ✨ | Detección del aterrizaje más confiable. |
| **3.0.10** | ✨ | Detección del despegue y separación de los tiempos de vuelo y de motor. |
| **3.0.9** | 🎨 | Instrucciones de conexión más claras. |
| **3.0.8** | 🔧 | Recuperación de la configuración cuando llega incompleta. |
| **3.0.7** | 🎨 | Botón "Cómo conectar" más compacto. |
| **3.0.6** | 🔧 | La ventana "Cómo conectar" se cierra correctamente. |
| **3.0.5** | ✨ | Instrucciones de conexión en una ventana independiente. |
| **3.0.4** | 🎨 | Estado del equipo más fácil de interpretar. |
| **3.0.3** | 🎨 | Panel de estado más compacto. |
| **3.0.2** | ✨ | Nuevo panel de estado del equipo. |
| **3.0.1** | ✨ | Configuración de la pantalla desde la web. |
| **3.0** | 🎨 | Indica si el equipo posee pantalla. |
| **2.9.23** | 🔧 | Corrección del aviso de actualización. |
| **2.9.22** | 🔧 | La web carga siempre la versión más reciente. |
| **2.9.21** | ✨ | El botón Ignorar recuerda la elección. |
| **2.9.20** | ✨ | El aviso de actualización se verifica al conectar. |
| **2.9.19** | ✨ | Verificación automática de la versión de la web. |
| **2.9.18** | ✨ | Aviso de actualización e información del autor. |
| **2.9.17** | 🎨 | El tiempo del gráfico comienza en el arranque del motor. |
| **2.9.16** | 🔧 | Se corrigió un reintento que afectaba la conexión. |
| **2.9.15** | 🔧 | Recuperación de la configuración incompleta. |
| **2.9.14** | 🎨 | Opciones útiles activadas de forma predeterminada. |
| **2.9.13** | 🎨 | Escala de altura protegida e indicación de vuelo válido/nulo mejor ubicada. |
| **2.9.12** | 🎨 | Tiempo de vuelo también expresado en minutos. |
| **2.9.11** | ✨ | Búsqueda manual de actualizaciones. |
| **2.9.10** | ✨ | Más pines disponibles en la configuración. |
| **2.9.9** | 🎨 | Gráfico más limpio. |
| **2.9.8** | 🔧 | El recorte del gráfico se mantiene al ampliar. |
| **2.9.7** | 🎨 | Resumen del vuelo mejor organizado. |
| **2.9.6** | ✨ | Cálculo del tiempo de planeo. |
| **2.9.5** | ✨ | Cálculo de la altura por inercia más confiable. |
| **2.9.4** | 🎨 | Gráfico de mayor altura. |
| **2.9.3** | ✨ | Cálculo de la altura ganada por inercia. |
| **2.9.2** | 🎨 | Ayudas de configuración y consola oculta. |
| **2.9.1** | 🎨 | Indicación de pérdidas de señal en el gráfico. |
| **2.9** | ✨ | Análisis del corte y validez del vuelo. |
| **2.8.3** | 🔧 | La web recupera el estado de diagnóstico. |
| **2.8.2** | 🎨 | Estado de diagnóstico siempre visible. |
| **2.8.1** | ✨ | Control del diagnóstico desde la web. |
| **2.8** | ✨ | Gráfico con altura y señales del motor. |
| **2.7.1** | ✨ | El umbral del motor se obtiene del equipo. |
| **2.7** | 🎨 | Altura del gráfico coloreada según el motor. |
| **2.6.5** | 🎨 | La sección de configuración se inicia contraída. |
| **2.6.4** | 🎨 | Botón "Borrar todos" siempre visible. |
| **2.6.3** | ✨ | Borrado completo y aviso de memoria casi llena. |
| **2.6.2** | 🔧 | Aviso cuando la memoria no está disponible. |
| **2.6.1** | ✨ | Barra de uso de la memoria. |
| **2.6** | ✨ | Archivos de vuelo con información de las señales. |
| **2.5.1** | 🎨 | Opciones avanzadas reorganizadas. |
| **2.5** | 🎨 | Escala automática de altura. |
| **2.4** | 🔧 | El monitor de señal muestra datos solo con señal válida. |
| **2.3** | ✨ | Límites del reglamento protegidos. |
| **2.2** | ✨ | Configuración de los valores de corte. |
| **2.1** | ✨ | Selección de pines desde la web. |
